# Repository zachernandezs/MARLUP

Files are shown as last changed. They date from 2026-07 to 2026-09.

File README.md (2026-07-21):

# MARLUP

MARLUP

Plataforma marina autoestabilizada para el lanzamiento de cohetes: 3 actuadores compensan roll, pitch y heave ante el oleaje. Desarrollado por **TECSpace**, la organización estudiantil de ingeniería aeroespacial del Instituto Tecnológico de Costa Rica (TEC).

## Índice

- [Contexto y evolución del proyecto](#contexto-y-evolución-del-proyecto)
- [Arquitectura física](#arquitectura-física)
  - [Geometría de la pirámide invertida](#geometría-de-la-pirámide-invertida)
  - [Modelo en espacio de estados](#modelo-en-espacio-de-estados)
  - [Actuadores](#actuadores)
  - [Sensores](#sensores)
  - [Perturbación por oleaje](#perturbación-por-oleaje)
- [Estrategia de control](#estrategia-de-control)
  - [LQR y matrices de ponderación](#lqr-y-matrices-de-ponderación)
  - [Filtro de Kalman discreto](#filtro-de-kalman-discreto)
  - [Extensión LQI (integrador de error)](#extensión-lqi-integrador-de-error)
  - [Precompensación / estado estacionario](#precompensación--estado-estacionario)
  - [Verificación PIL / SIL](#verificación-pil--sil)
- [Resultados de simulación](#resultados-de-simulación)
- [Estructura del repositorio](#estructura-del-repositorio)
- [Cómo ejecutar el modelo](#cómo-ejecutar-el-modelo)
- [Informes técnicos](#informes-técnicos)
- [Equipo](#equipo)

## Contexto y evolución del proyecto

El proyecto se ha desarrollado en dos etapas dentro del curso de Control:

| Etapa | Autoras/es | Alcance |
|---|---|---|
| **1 — Modelado inicial** | Hillary González González, Kendall Guerrero González | Modelado de la plataforma en *Simscape Multibody* (planta con pistones ideales, sensor ideal sin ruido) y control **PID individual por eje**. Solo simulación, sin prototipo físico. |
| **2 — Control óptimo** | Álvaro Pérez Mora, William Smith Hernández | Aproximación teórica simplificada de la planta, controlada con **LQR + estimador de Kalman**, y verificación del mismo controlador contra la planta simulada. Implementación en *Processor in the Loop* (PIL) sobre un Arduino MEGA. |

El repositorio actual (`MODELS/`) continúa esta línea de trabajo y **extiende el controlador LQR de la Etapa 2 con un integrador de error (LQI)**, para eliminar el error de estado estacionario sin depender únicamente de la precompensación *feedforward*.

La plataforma se modela como un sistema **MIMO no lineal** con tres actuadores lineales independientes cuya acción conjunta mantiene el plato superior nivelado.

## Arquitectura física

El sistema consiste en un plato circular superior (masa `M`, momentos de inercia `Jx`, `Jy`) sostenido por tres actuadores lineales dispuestos sobre una **pirámide triangular invertida**, anclada a la estructura de flotación de MARLUP.

### Geometría de la pirámide invertida

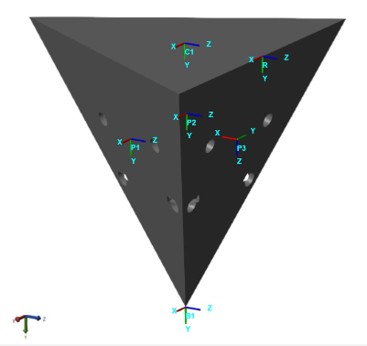
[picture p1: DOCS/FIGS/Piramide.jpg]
Esquema de la pirámide triangular invertida que sostiene el plato


*Esquema de la pirámide triangular invertida: los actuadores se ubican en las caras P1, P2, P3, con marco de referencia global R y marco del plato C1.*

**Dimensiones de la pirámide:**

- Altura: $H = 0.11\text{ m}$
- Radio circunscrito de la base: $R_b = 0.13\text{ m}$
- Radio de los puntos de aplicación en el plato: $R_t = 0.65\text{ m}$
- Ángulos de los actuadores sobre el plato: $\phi = \{-30°,\ 90°,\ 210°\}$

Los actuadores empujan perpendicularmente a cada cara de la pirámide. La componente vertical del vector unitario de empuje es común a los tres actuadores:

$$u_z = \frac{R_b}{\sqrt{R_b^2 + 4H^2}} \approx 0.5087$$

Cada punto de aplicación sobre el plato, respecto a su centroide, es:

$$\Delta \mathbf{r}_i = \begin{bmatrix} R_t \cos\phi_i \\ R_t \sin\phi_i \\ 0 \end{bmatrix}$$

Los esfuerzos generalizados del sistema $(\tau_x, \tau_y, F_z)$ se obtienen de las fuerzas de los tres actuadores $(F_1, F_2, F_3)$ mediante la **matriz de transformación** $T$:

$$\begin{bmatrix} \tau_x \\ \tau_y \\ F_z \end{bmatrix} = T \begin{bmatrix} F_1 \\ F_2 \\ F_3 \end{bmatrix}, \qquad T_i = \begin{bmatrix} R_t \sin\phi_i\, u_z \\ -R_t \cos\phi_i\, u_z \\ u_z \end{bmatrix}$$

Para $\phi = \{-30°, 90°, 210°\}$:

$$T = u_z \begin{bmatrix} -0.5 R_t & R_t & -0.5 R_t \\ -0.866 R_t & 0 & 0.866 R_t \\ 1 & 1 & 1 \end{bmatrix}$$

Para el reparto de fuerzas deseadas entre los tres actuadores se usa la pseudoinversa de $T$:

$$F = T^{+}\, u_{\text{des}}, \qquad T^{+} = \operatorname{pinv}(T)$$

### Modelo en espacio de estados

Considerando únicamente roll, pitch y heave, sin amortiguamiento ni rigidez, la dinámica del plato es un sistema lineal de segundo orden desacoplado:

$$J_x\ddot{\alpha} = \tau_x, \qquad J_y\ddot{\theta} = \tau_y, \qquad M\ddot{z} = F_z$$

En espacio de estados, $\dot{x} = Ax + Bu,\ \ y = Cx + Du$, con:

$$x = \begin{bmatrix}\alpha & \dot\alpha & \theta & \dot\theta & z & \dot z\end{bmatrix}^\top,\qquad u = \begin{bmatrix}\tau_x & \tau_y & F_z\end{bmatrix}^\top,\qquad y = \begin{bmatrix}\alpha & \theta & z\end{bmatrix}^\top$$

$$A = \begin{bmatrix} 0&1&0&0&0&0\\0&0&0&0&0&0\\0&0&0&1&0&0\\0&0&0&0&0&0\\0&0&0&0&0&1\\0&0&0&0&0&0 \end{bmatrix},\quad B = \begin{bmatrix} 0&0&0\\1/J_x&0&0\\0&0&0\\0&1/J_y&0\\0&0&0\\0&0&1/M \end{bmatrix},\quad C = \begin{bmatrix} 1&0&0&0&0&0\\0&0&1&0&0&0\\0&0&0&0&1&0 \end{bmatrix}$$

El sistema es controlable ($\operatorname{rank}(\operatorname{ctrb}(A,B)) = 6$) y se discretiza con retenedor de orden cero (ZOH) a un período de muestreo global $T_s = 0.01\text{ s}$, obteniendo $(A_d, B_d, C_d, D_d)$.

### Actuadores

Los actuadores planteados para la planta son cilindros **hidráulicos lineales Rexroth CDH1 MP3** (Bosch), seleccionados por su confiabilidad, estabilidad y capacidad de respuestas rápidas con fuerza significativa.

| Parámetro | Valor |
|---|---|
| Recorrido máximo del pistón | 1 m |
| Longitud total del actuador | 2 m |
| Presión del sistema | 250 bar |
| Área del pistón | 12.5 cm² |
| Área del anillo | 6.4 cm² |
| Carga aplicada | 58.19 kg |
| Alimentación eléctrica | 24 V DC a 200 mA |
| Desviación lineal | ≤ 500 mm |
| Resolución | 100 μm |

En el modelo teórico actual del repositorio, los actuadores se representan como ganancias ideales (torques/fuerza aplicados directamente a la planta); la dinámica realista del pistón (fricción, saturación, ancho de banda) se modeló por separado en Simscape durante la Etapa 2, pero no forma parte del modelo idealizado activo en `MODELS/`.

### Sensores

El sensado no ideal se modela con dos dispositivos:

- **3DM-GX5 AHRS** — entrega roll y pitch, con ruido blanco de banda limitada (BLWN) sumado a la señal.
- **MB1040** (ultrasónico) — entrega heave, con cuantización de 1 pulgada de resolución más ruido BLWN.

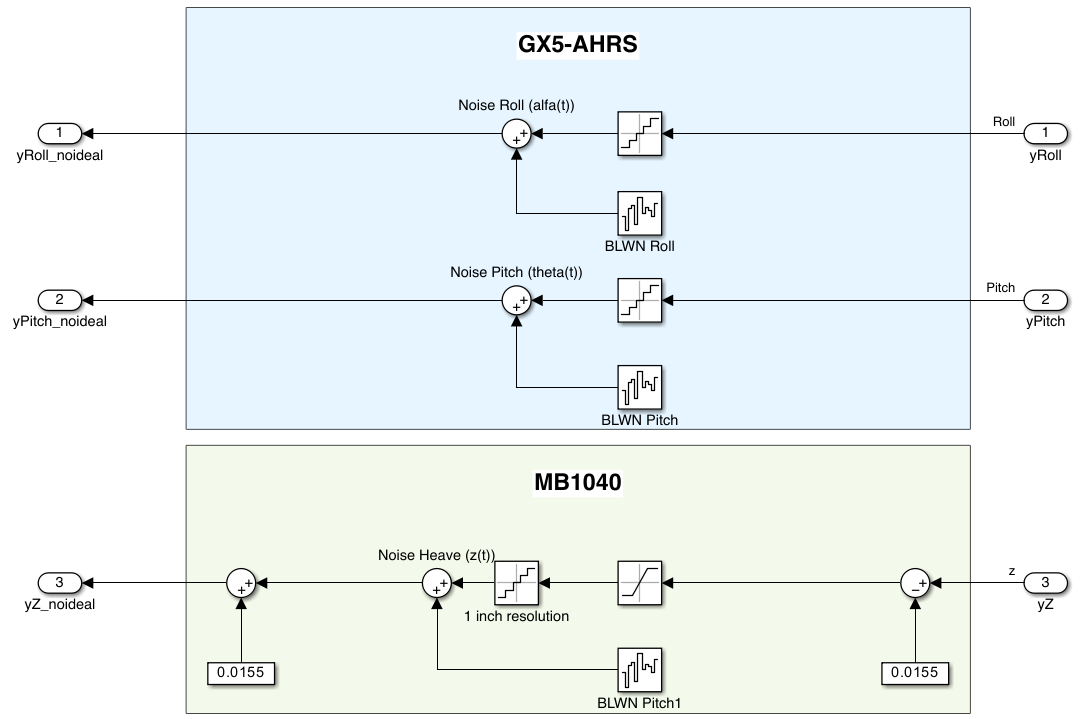
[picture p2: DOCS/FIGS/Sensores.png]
Modelo no ideal de los sensores seleccionados


*Modelo Simulink de los sensores no ideales: AHRS para roll/pitch y sensor ultrasónico para heave.*

### Perturbación por oleaje

El oleaje se modela como un disturbio de **salida**, no de estado:

$$y_{\text{total}} = Cx + P_{\text{reorder}}\, y_{\text{amb}}$$

El subsistema de oleaje entrega sus salidas en el orden `[heave; pitch; roll]`, mientras el modelo espera `[roll; pitch; heave]`; `P_reorder` corrige ese orden antes de sumar la perturbación.

La energía del oleaje se distribuye según el espectro de **Pierson-Moskowitz**, adecuado para mar completamente desarrollado (sin dependencia del viento):

$$S_\eta(\omega) = \frac{5}{16}\,\frac{H_s^2\,\omega_p^4}{\omega^5}\exp\!\left[-\frac{5}{4}\left(\frac{\omega_p}{\omega}\right)^{4}\right]$$

donde $\omega_p$ es la frecuencia pico del espectro y $H_s$ la altura significativa de ola. Este espectro se combina con una función de dispersión direccional (coseno cuadrado) para generar el oleaje 3D que perturba el eje $z$ y, mediante sus derivadas parciales en $x$ y $y$, los ángulos de roll y pitch.

## Estrategia de control

### LQR y matrices de ponderación

El controlador base es un **regulador lineal cuadrático (LQR)**: penaliza fuertemente el error de heave, medianamente el error angular, y levemente las velocidades y el esfuerzo de control.

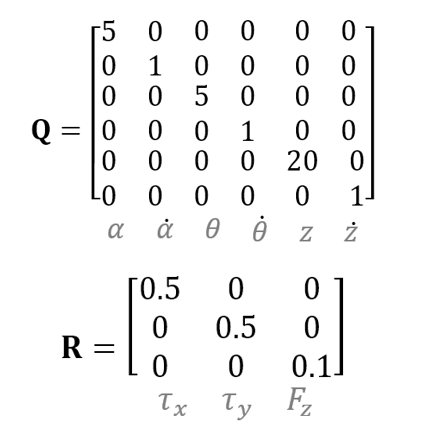
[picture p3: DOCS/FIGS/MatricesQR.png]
Matrices de ponderación Q y R del diseño LQR documentado en el informe


*Matrices $Q$ y $R$ del diseño LQR documentado en el informe de la Etapa 2. La implementación actual en `MODELS/marlup_init.m` reutiliza esta misma estructura de penalización, pero con ganancias reajustadas para el diseño LQI (ver más abajo).*

### Filtro de Kalman discreto

Dado que solo se sensan roll, pitch y heave (no sus velocidades), se requiere un estimador para reconstruir el vector de estado completo. Se emplea un **filtro de Kalman discreto** obtenido con `dlqe`:

$$\hat{x}(k+1\mid k) = A_d\,\hat{x}(k\mid k) + B_d\,u(k)$$

$$\hat{x}(k+1\mid k+1) = \hat{x}(k+1\mid k) + L_d\,\big(y(k+1) - C_d\,\hat{x}(k+1\mid k)\big)$$

La covarianza de proceso $Q_x$ pondera más las velocidades (mayor incertidumbre), y la de medición $R_n$ refleja el ruido real de los sensores: 0.5° en roll/pitch, 3 mm en heave.

### Extensión LQI (integrador de error)

Para eliminar el error de estado estacionario ante perturbaciones sostenidas de oleaje, el repositorio **aumenta la planta discreta con un integrador de error** por salida y diseña una ganancia LQI:

$$A_{\text{aug}} = \begin{bmatrix} A_d & 0 \\ -C_d A_d & I \end{bmatrix},\qquad B_{\text{aug}} = \begin{bmatrix} B_d \\ -C_d B_d \end{bmatrix}$$

$$K_{\text{aug}} = \operatorname{dlqr}(A_{\text{aug}}, B_{\text{aug}}, Q_{\text{aug}}, R) = \begin{bmatrix} K_x & K_i \end{bmatrix}$$

$$u(k) = -K_x\,\hat{x}(k) - K_i\, z_I(k), \qquad z_I(k) = \sum e(k),\ \ e = r - y_{\text{total}}$$

El diseño se valida además con la función `lqi` de MATLAB sobre el sistema discretizado como verificación cruzada. El diseño LQR continuo (`K`), su observador (`L`) y la ganancia de precompensación (`Kr`) se conservan como variante **sin integrador**; `Kr` no debe combinarse con el control LQI.

### Precompensación / estado estacionario

Para la variante sin integrador, el valor de estado estacionario se fija con una matriz *feedforward* $K_r$, resuelta de forma que $y_{ss} = r$:

$$y_{ss} = C\big(-(A-BK)^{-1}B\,K_r\big)r = r \quad\Longrightarrow\quad K_r = \operatorname{pinv}\!\big(C(-(A-BK)^{-1})B\big)$$

### Verificación PIL / SIL

El controlador LQR y el filtro de Kalman se validaron ejecutándolos en un **Arduino MEGA** mediante *Processor in the Loop* (PIL), en comunicación constante con la PC que simula el resto de la planta. Un interruptor en Simulink permite alternar entre PIL y *Software in the Loop* (SIL) para comparar ambas respuestas contra la misma simulación.

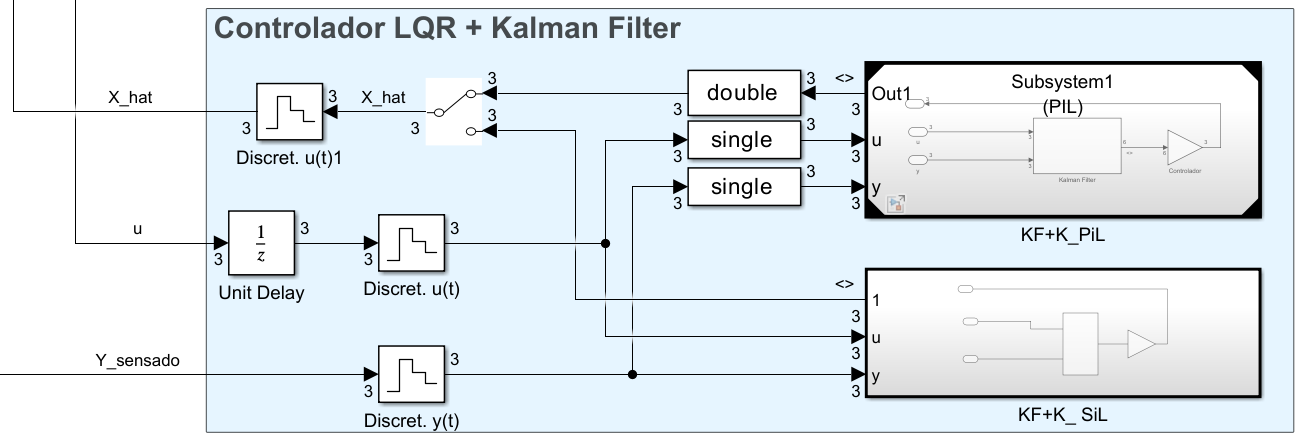
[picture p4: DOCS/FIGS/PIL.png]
Controlador LQR + Kalman Filter en configuración PIL y SIL


*Bloque de control en Simulink con las rutas PIL (ejecución en Arduino MEGA) y SIL (ejecución en PC), comparadas en paralelo.*

## Resultados de simulación

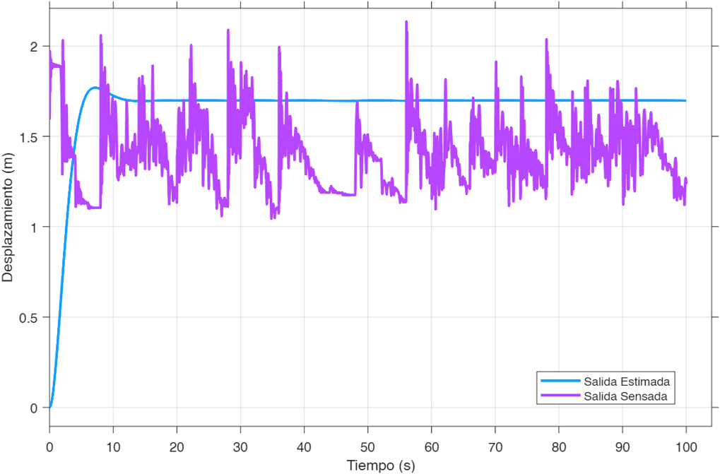
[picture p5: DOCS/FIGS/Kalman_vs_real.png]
Salida estimada del filtro de Kalman contra la salida sensada


*Heave: salida sensada (con ruido) contra la salida estimada por el filtro de Kalman, que filtra el ruido de medición y converge a la referencia.*

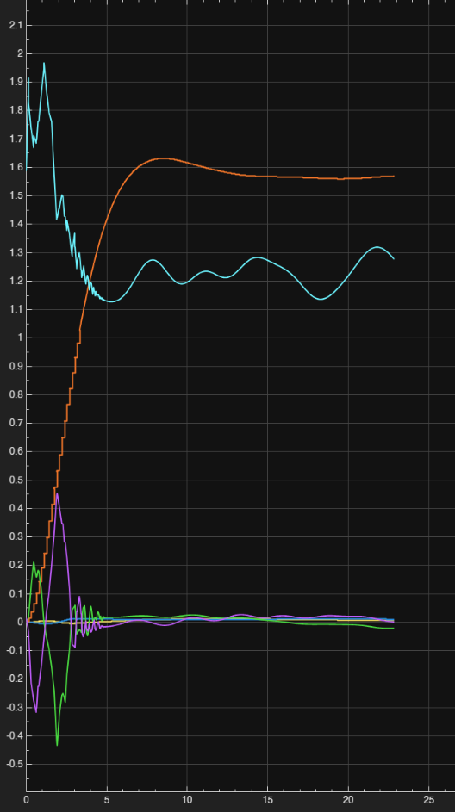
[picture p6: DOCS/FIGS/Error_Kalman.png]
Transitorio de estimación del filtro de Kalman


*Transitorio de estimación: las variables estimadas convergen desde la condición inicial hacia sus valores sensados, con el error de estimación decreciendo en el tiempo.*

Videos adicionales de las simulaciones (respuesta del modelo teórico, comparación con y sin Kalman, corridas fallidas de depuración) están disponibles en [`DOCS/FIGS/`](DOCS/FIGS/).

## Estructura del repositorio

```
MARLUP/
├── CAD/          Piezas SolidWorks (.SLDPRT) y ensamble principal (.SLDASM)
│                 usados por los bloques File Solid del modelo Simulink.
├── DOCS/         Informes finales (PDF) y DOCS/FIGS/ con figuras y videos de resultados.
├── MODELS/       Script MATLAB (marlup_init.m) + modelo Simulink (marlup_model.slx) activos.
└── EXPERIMENTS/  Copias de trabajo por integrante (Aaron/, Alvaro/, Will/) para
                  probar ajustes de ganancias de forma independiente.
```

## Cómo ejecutar el modelo

1. Abrir MATLAB en la raíz del repositorio y ejecutar `MODELS/marlup_init.m`. Esto define la planta, discretiza el sistema, calcula el filtro de Kalman y las ganancias de control, y las deja en el *workspace* (`Ad`, `Bd`, `Cd`, `Kx`, `Ki`, `Ld`, `T`, `Tinv`, `P_reorder`, etc.). También agrega `CAD/` al *path* para que el modelo encuentre la geometría por nombre.
2. Abrir `MODELS/marlup_model.slx` y correr la simulación — el modelo lee las variables anteriores del *workspace* base, por lo que falla si el script no se ejecutó antes en la misma sesión.
3. Todos los bloques discretos del modelo deben usar el mismo período de muestreo `Ts` definido en el script (`0.01 s`).

No hay sistema de *build*, gestor de paquetes ni suite de pruebas: todo el flujo vive dentro de MATLAB/Simulink.

## Informes técnicos

- [`DOCS/Final_Alvaro_Perez_William_Smith.pdf`](DOCS/Final_Alvaro_Perez_William_Smith.pdf) — *Avance Final MARLUP, Control Stage 2*: modelado teórico de la planta, diseño LQR + Kalman, actuadores, sensores, oleaje y verificación PIL/SIL.
- [`DOCS/InformeFinal_Proyecto_Lab_Control.pdf`](DOCS/InformeFinal_Proyecto_Lab_Control.pdf) — *Sistema de Control Activo para la Estabilización de la Plataforma MARLUP*: modelado inicial en Simscape Multibody y control PID individual por eje.

## Equipo

**TECSpace**, organización estudiantil de ingeniería aeroespacial del Instituto Tecnológico de Costa Rica (ITCR).

- Hillary González González, Kendall Guerrero González — Etapa 1 (modelado y PID).
- Álvaro Pérez Mora, William Smith Hernández — Etapa 2 (LQR + Kalman, PIL/SIL).
- Aaron, Álvaro, Will — ajuste de ganancias y experimentación continua (`EXPERIMENTS/`).

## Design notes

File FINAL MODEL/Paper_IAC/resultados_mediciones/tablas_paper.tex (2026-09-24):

% Tabla 7 (caso NORMAL): base & placa & reducción
Roll RMS & 0.3769 & 0.01994 & 18.9 (25.5 dB) \\
Pitch RMS & 0.1601 & 0.08101 & 2.0 (5.9 dB) \\
Heave RMS & 0.07018 & 0.07675 & 0.9 (-0.8 dB) \\
Roll peak & 0.7134 & 0.03903 & 18.3 \\
Pitch peak & 0.3765 & 0.1585 & 2.4 \\
Heave peak & 0.1245 & 0.09785 & 1.3 \\
Force range [min, max]: [203, 332] N (11.1 % de la capacidad)
Yaw drift: -0.128 deg (max 0.253 deg)

% Atenuación en w_p medida vs |S(jw_p)| (Tabla 6)
medido [roll pitch heave] = [-24.1 -11.1 -10.4] dB; teórico = [-31.2 -31.2 -37.8] dB

% Costo de cómputo por 10 s simulados (Tabla 8)
normal: 48.7 s

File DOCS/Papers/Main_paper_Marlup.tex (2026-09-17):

% ==================================================================
% IAC-26-D2.2.12.x114322 -- MARLUP paper skeleton
% Limit: 15 pages (US Letter, two columns), including abstract,
% figures and references; PDF only, max 5 MB; deadline 14 Sep 2026.
%
% Current length with placeholders: see compiled PDF (target <= 11 pages
% before the PiL and wave results are written; hard limit 15).
%
% Figures in pics/ (PNG). "real" = rendered from the TikZ/pgfplots
% sources in figsrc/ (data from the identification/LQR document);
% "placeholder" = to be replaced keeping the file name.
%   fig01_marlup_concept        placeholder  CAD render of the platform
%   fig02_geometry              real         side/top geometry
%   fig03_wave_disturbance      placeholder  P-M base motion
%   fig04_uz_comparison         real         assumed vs measured u_z
%   fig05_digital_twin          placeholder  Simscape Multibody model
%   fig06_ident_setup           real         identification configuration
%   fig07_ident_fit             real         roll-rate traces, fit window
%   fig08_poles                 real         closed-loop eigenvalues
%   fig09_control_architecture  real         closed loop with KF
%   fig10_pil_setup             placeholder  host PC <-> microcontroller
%   fig11_sil_vs_pil            placeholder  SiL vs PiL responses
%   fig12_sensitivity           real         |S(jw)| with P-M spectrum
%   fig13_step_forces           real         step responses + forces
%   fig14_digital_twin_waves    placeholder  double column, wave results
% Search for \todo{ and "TODO" to find every open item.
% ==================================================================
\documentclass[]{IAC_style}

% ------------------------------------------------------------------
% Additional packages (the class already loads graphicx, float,
% tabularx, booktabs, hyperref, cite and newtx fonts)
% ------------------------------------------------------------------
\usepackage{amsmath,bm} % symbols come from newtxmath (amssymb clashes with it)
\usepackage{xcolor}

% Editorial marker: prints red notes in the draft.
% For the final version replace the definition by \newcommand{\todo}[1]{}
\newcommand{\todo}[1]{\textcolor{red}{\textbf{[TODO:} #1\textbf{]}}}

% Notation
\newcommand{\W}{\bm{W}}
\newcommand{\Amat}{\bm{A}}
\newcommand{\Bmat}{\bm{B}}
\newcommand{\Cmat}{\bm{C}}
\newcommand{\Kmat}{\bm{K}}
\newcommand{\Mmat}{\bm{M}}
\newcommand{\Jmat}{\bm{J}}
\newcommand{\qv}{\bm{q}}
\newcommand{\xv}{\bm{x}}
\newcommand{\uv}{\bm{u}}
\newcommand{\Fv}{\bm{F}}
\newcommand{\cv}{\bm{c}}
\newcommand{\dd}{\mathrm{d}}
\newcommand{\un}[1]{\,\mathrm{#1}}
\newcolumntype{L}{>{\raggedright\arraybackslash}X}
\newcommand{\nom}[2]{\par\noindent\hangindent=2.6cm\hangafter=1\makebox[2.6cm][l]{#1}#2}

\begin{document}

\IACpaperyear{2026}
\IACconference{77}
\IACpapernumber{IAC-26,D2,2,12,x114322}
\IAClocation{Antalya, T\"urkiye}
\IACdate{5-9 October 2026}

% Copyright form B1 (retained by the author). Confirm the form selected
% in the IAF upload system; the wording must match it exactly.
\IACcopyrightB{Mr. \'Alvaro P\'erez Mora}

% Title must be identical to the accepted abstract.
\title{Development of an Actively Stabilized Marine Launch Platform for Small Rocket Launch Operations}

%\IACauthor{Author name}{affiliation index}{is corresponding author? 0-1}
\IACauthor{\'Alvaro P\'erez Mora$^{\orcidlink{0009-0004-1847-6741}}$}{2}{1}
\IACauthor{Aar\'on David Salas Alvarado$^{\orcidlink{0009-0001-7957-4546}}$}{2}{1} % TODO: add \orcidlink if available
\IACauthor{William Smith Hern\'andez$^{\orcidlink{0009-0003-1756-4718}}$}{2}{1}    % TODO: add \orcidlink if available

\IACauthoraffiliation{School of Electronics Engineering,Technical Institute of Costa Rica (ITCR), Cartago, Costa Rica.} % TODO: confirm e-mails

\abstract{
Costa Rica is a small contry of around 51,100 square kilometers of area, and it has extensive protected regions and scarce flat terrain, which constrains ground-based launch infrastructure and motivates alternative launch architectures. The MARLUP (Marine Launchpad) project proposes an actively stabilized floating launch platform for small rockets (motor classes A through H). The launch platform is based on a Stewart-type mechanism, with three linear actuators that control the roll, pitch and vertical displacement (heave) of the top plate, and mitigate the dominant disturbances induced by waves and tide. The dynamics were formulated from rigid-body mechanics as a nonlinear multi-input multi-output system and cast in state-space form. A digital twin was implemented in MATLAB/Simulink with Simscape Multibody from CAD geometry, including noisy, quantized and sampled sensor models and calm-sea disturbances generated from a Pierson-Moskowitz spectrum with directional spreading. Since the simplified analytic model used in earlier stages misrepresented the effective actuator geometry and inertia of the closed-chain mechanism, the force-to-acceleration map of the platform was identified directly from the digital twin through four short simulations and validated against an independent superposition prediction. On the identified model, an integral linear quadratic regulator with closed-form weights places the closed-loop bandwidth five to six times above the wave spectral peak, and a state estimator reconstructs the unmeasured states. The controller was discretized and executed in a Processor-in-the-Loop configuration, running on an embedded microcontroller while the digital twin was simulated in real time on a host computer. Compared with the previous decentralized and model-based control stages, the proposed strategy raises the wave attenuation at the spectral peak from $6$ dB to between $31$ and $38$ dB, settles within approximately $10$ s with minimal overshoot while holding the commanded heave, and reduces the simulation cost from hours to minutes. These results demonstrate the feasibility of an actively stabilized floating launch platform and establish a validated digital twin and control architecture for future experimental work and maritime launch infrastructure in emerging space nations.
}

\maketitle
\thispagestyle{fancy}

% ==================================================================
\section*{Nomenclature}
% Breakable list (a tabular cannot split across columns)
\nom{$\alpha,\ \theta$}{roll and pitch angles of the plate (rad)}
\nom{$z$}{heave, plate height (m)}
\nom{$\qv$}{generalized coordinates $[\alpha\ \theta\ z]^\top$}
\nom{$\xv$}{state vector $[\alpha\ \dot\alpha\ \theta\ \dot\theta\ z\ \dot z]^\top$}
\nom{$\Fv$}{actuator force vector $[F_1\ F_2\ F_3]^\top$ (N)}
\nom{$\Fv_\mathrm{trim}$}{static equilibrium force vector (N)}
\nom{$\W$}{force-to-acceleration map ($3\times3$)}
\nom{$\cv$}{gravitational bias acceleration}
\nom{$\Mmat(\qv),\ \Jmat(\qv)$}{generalized inertia matrix, inverse-kinematics Jacobian}
\nom{$\bm{\xi}$}{integral state}
\nom{$H_s,\ T_p,\ \omega_p$}{significant wave height, peak period, peak frequency}
\nom{$\omega_n,\ \zeta,\ \omega_i$}{closed-loop natural frequency, damping ratio, integrator pole}
\nom{$u_z$}{vertical direction cosine of an actuator}
\nom{$T_s$}{controller sampling period (s)}
\par

\section*{Acronyms/Abbreviations}
Attitude and heading reference system (AHRS), degree of freedom (DOF), Kalman filter (KF), linear quadratic regulator (LQR), Marine Launchpad (MARLUP), multi-input multi-output (MIMO), Pierson--Moskowitz (P--M), Processor-in-the-Loop (PiL), Software-in-the-Loop (SiL), zero-order hold (ZOH).

% ==================================================================
\section{Introduction}
\label{sec:intro}
Access to launch infrastructure remains one of the main barriers for emerging space nations. Ground-based launch sites require large uninhabited areas, safety exclusion zones along the flight corridor and stable, flat terrain. Costa Rica combines a small national territory, a large fraction of land under environmental protection and a mountainous topography, which makes a conventional launch range, even for small suborbital vehicles, difficult to justify. % TODO: add a source for land area and protected-area fraction (e.g., SINAC).
Launching from the sea removes most of these constraints, since the launch site can be relocated to open water where range safety is easier to guarantee.

Sea-based launch has precedents at very different scales, from the fixed San Marco platform off the coast of Kenya to the floating Sea Launch system and the more recent ship-based launches of small orbital vehicles \cite{sanmarco,sealaunch}. For small rockets, however, the floating base is itself a moving support: wave-induced roll, pitch and heave perturb the alignment of the launch rail and the initial attitude of the vehicle at lift-off. Parallel mechanisms derived from the Stewart platform \cite{stewart1965,dasgupta2000,merlet2006} are the established solution for compensating such motions, and active motion compensation is routinely used offshore, for example in motion-compensated gangways for wind turbine access \cite{cerda2010}. A reduced three-actuator architecture that controls only roll, pitch and heave addresses the motions that dominate launch alignment while keeping mass, cost and power consumption compatible with a student-led project.

The MARLUP project, developed within TECSpace at the Instituto Tecnol\'ogico de Costa Rica, follows this approach. The hexagonal floating base was sized from buoyancy and stability criteria \cite{perez2025flot}. A first Simscape Multibody model of the stabilization mechanism was controlled with one decentralized PID loop per axis, under sinusoidal waves and ideal sensors, and required several hours of computation for a few seconds of response \cite{gonzalez2025}. A second stage replaced the PID loops with a linear quadratic regulator (LQR) and a KF designed on a simplified analytic model, added a P--M wave model and non-ideal sensors, and executed the controller on a microcontroller in a PiL configuration; applied to the multibody digital twin, however, this controller achieved only marginal stability for about 20 s \cite{perez2025stage2}. The recommendation of that stage was to identify the simulated plant instead of assuming it.

This paper reports the resulting design. Its contributions are a digital twin of the platform with realistic disturbances and sensing, a diagnosis of why the rigid-body simplification commonly used for such platforms fails for a closed-chain mechanism whose legs are comparable in size to the plate, a non-invasive identification procedure that is exact at the operating point and is validated by an independent prediction, an integral LQR with closed-form weights whose bandwidth is placed deliberately with respect to the wave spectrum, and the execution of the discretized controller and estimator in PiL. Section~\ref{sec:system} describes the system and its environment, Section~\ref{sec:model} the dynamic model, Section~\ref{sec:ident} the identification, Section~\ref{sec:control} the control and estimation design, Section~\ref{sec:pil} the PiL implementation, Section~\ref{sec:results} the results, and Section~\ref{sec:concl} the conclusions.

% ==================================================================
\section{System description}
\label{sec:system}

\subsection{Launch platform concept}
The MARLUP concept, shown in Fig.~\ref{fig:cad}, consists of a hexagonal floating base with six lateral floats and a central float, sized by Archimedes' principle to carry the structure, the launch plate and the lift-off load with a $25\%$ margin \cite{perez2025flot}. The stabilization mechanism is mounted on the floating base and carries the launch plate, which must remain level and at a commanded height during launch preparation and lift-off. The operating envelope is restricted to calm-sea launch windows. \todo{state the design sea state ($H_s$ range) and the target rocket envelope (mass, rail length).}

\begin{figure}[H]
\centering

\caption{MARLUP concept: hexagonal floating base, three-actuator stabilization mechanism and launch plate (SolidWorks model).}
\label{fig:cad}
\end{figure}

\subsection{Stabilization mechanism}
The moving platform is a circular plate of mass $M=67.7\un{kg}$ carried by three linear actuators (Fig.~\ref{fig:geom}). The lower anchors lie on a small inverted triangular pyramid ($H=0.11\un{m}$, circumscribed radius $R_b=0.13\un{m}$) attached to the floating structure through a four-DOF joint. The upper anchors are distributed on a circle of radius $R_t=0.65\un{m}$ at azimuths $\varphi_i=\{-30^\circ,90^\circ,210^\circ\}$, and the plate rests at $z_0=1.5716\un{m}$ in the assembled configuration. The actuators are modeled after a double-acting hydraulic cylinder (Bosch Rexroth CDH1 MP3, $250$ bar, $12.5\un{cm^2}$ piston area, $\pm0.28\un{m}$ usable stroke) and are represented in the digital twin as ideal force sources. The controlled coordinates are $\qv=[\alpha\ \theta\ z]^\top$.

\begin{figure}[H]
\centering

\caption{Geometry of the stabilization mechanism (schematic, not to scale): side view with the measured actuator inclination of $34.3^\circ$ from vertical, and top view of the plate anchors.}
\label{fig:geom}
\end{figure}

\subsection{Sensing}
Roll and pitch are measured by an AHRS model based on the 3DM-GX5 and heave by an ultrasonic range sensor model based on the MB1040. Each measurement includes additive white Gaussian noise and quantization, and all signals are sampled at $T_s=10\un{ms}$, the period of the PiL target. \todo{list noise standard deviations and quantization steps used.}

\subsection{Wave disturbance model}
The sea state is generated from the P--M spectrum \cite{pm1964,fossen2011},
\begin{equation}
S_\eta(\omega)=\frac{5}{16}\,\frac{H_s^2\,\omega_p^4}{\omega^5}\exp\!\left[-\frac{5}{4}\left(\frac{\omega_p}{\omega}\right)^{4}\right],
\label{eq:pm}
\end{equation}
combined with a $\cos^2$ directional spreading function. The peak period $T_p=10\un{s}$ gives $\omega_p=2\pi/T_p=0.628\un{rad/s}$, the frequency that governs the control specification of Section~\ref{sec:control}. The free-surface elevation at the origin defines the heave of the base, and its spatial gradients define the base roll and pitch, which are imposed through the four-DOF joint (Fig.~\ref{fig:waves}). \todo{state $H_s$, number of wave components and seed.}

\begin{figure}[H]
\centering

\caption{Base motion generated by the P--M model ($T_p=10$ s): heave, roll and pitch imposed on the floating structure.}
\label{fig:waves}
\end{figure}

% ==================================================================
\section{Dynamic model and digital twin}
\label{sec:model}

\subsection{Rigid-body formulation}
For a rigid multibody mechanism with independent generalized coordinates $\qv$, Lagrangian mechanics gives \cite{merlet2006}
\begin{equation}
\Mmat(\qv)\,\ddot{\qv}+\bm{h}(\qv,\dot{\qv})=\Jmat(\qv)^\top\Fv .
\label{eq:eom}
\end{equation}
The generalized inertia matrix $\Mmat(\qv)=\sum_k\big[\Jmat_{v,k}^\top m_k\Jmat_{v,k}+\Jmat_{\omega,k}^\top\bm{I}_k\Jmat_{\omega,k}\big]$ contains every moving body (plate, upper triangle and leg segments). The vector $\bm{h}$ collects gravity and the Coriolis and centrifugal terms, the latter quadratic in $\dot{\qv}$. The inverse-kinematics Jacobian $\Jmat(\qv)=\partial\bm{\ell}/\partial\qv$, with $\bm{\ell}$ the leg lengths, has rows $\bm{u}_i^\top\partial\bm{p}_i/\partial\qv$, where $\bm{u}_i=(\bm{p}_i-\bm{b}_i)/\ell_i$ is the unit vector from the base anchor $\bm{b}_i$ to the plate anchor $\bm{p}_i$. Equation~\eqref{eq:eom} defines a nonlinear, configuration-dependent MIMO plant.

Evaluated at the assembled pose $\qv_0$ with the plate at rest, $\Mmat$, $\bm{h}$ and $\Jmat$ become constant and every velocity-dependent term vanishes identically, so that
\begin{equation}
\begin{gathered}
\ddot{\qv}=\W\Fv+\cv,\\
\W=\Mmat(\qv_0)^{-1}\Jmat(\qv_0)^\top,\qquad \cv=-\Mmat(\qv_0)^{-1}\bm{h}(\qv_0,\bm{0}).
\end{gathered}
\label{eq:affine}
\end{equation}
This affine relation between forces and accelerations is exact at that point, not a linearization; it only assumes rigid bodies and evaluation at rest, both of which hold by construction at the start of a simulation from the assembled configuration. The Gr\"ubler--Kutzbach criterion applied to the Simscape topology ($N=14$ links, $j=15$ joints, $\sum f_i=15$ joint freedoms) gives $6(N-1-j)+\sum f_i=3$ DOF for the plate. The yaw freedom of the base joint is unactuated and unmeasured, and lies outside the model.

\subsection{Limitations of the simplified analytic model}
\label{sec:whyfail}
The previous stage \cite{perez2025stage2} took the plate as a free rigid body, $J_x\ddot\alpha=\tau_x$, $J_y\ddot\theta=\tau_y$, $M\ddot z=F_z$, with the bare-plate inertias $J_x=J_y=6.194\un{kg\,m^2}$ and $M=67.71\un{kg}$, and mapped the actuator forces to generalized efforts through a constant allocation matrix,
\begin{equation}
\begin{bmatrix}\tau_x\\ \tau_y\\ F_z\end{bmatrix}=\bm{T}\Fv,\qquad
\bm{T}_{(:,i)}=u_z\begin{bmatrix}R_t\sin\varphi_i\\ -R_t\cos\varphi_i\\ 1\end{bmatrix},
\label{eq:Told}
\end{equation}
so that $\W_\mathrm{assumed}=\mathrm{diag}(J_x,J_y,M)^{-1}\bm{T}$. Both factors are incorrect, and independently so.

The vertical direction cosine was taken as that of the normal to a face of the base pyramid, $u_z=R_b/\sqrt{R_b^2+4H^2}=0.509$, which describes a real part of the mechanism but not the direction along which an actuator pushes. The actuators act along the line joining a base anchor to a plate anchor $1.57\un{m}$ above it, for which the assembled model gives $u_z=0.826$, i.e. $34.3^\circ$ instead of $59.4^\circ$ from vertical, a factor of $1.62$ (Fig.~\ref{fig:uz}). The inertia factor is wrong because the plate is the moving platform of a closed-chain mechanism: tilting it requires all legs to change length and swing, and translates the plate laterally, so every leg body contributes to $\Mmat$. With the analytic geometry, the tilt inertia consistent with the measurements of Section~\ref{sec:ident} is about $57.8\un{kg\,m^2}$, nine times the bare-plate value and plausibly bracketed by the bare disc ($6.2\un{kg\,m^2}$) and a $67.7\un{kg}$ point mass at the plate height ($mL^2=167\un{kg\,m^2}$).

\begin{figure}[H]
\centering

\caption{Candidate actuator directions. The simplified model used the normal to a face of the base pyramid; the actuators run between anchors. Their vertical projections differ by a factor of $1.62$.}
\label{fig:uz}
\end{figure}

Scaling the identified map back through the nominal inertias, $\bm{T}_\mathrm{ident}=\mathrm{diag}(J_x,J_y,M)\W$, allows a direct comparison,
\begin{equation}
\begin{gathered}
\bm{T}_\mathrm{assumed}=\begin{bmatrix}
-0.165 & 0.331 & -0.165\\
-0.286 & 0 & 0.286\\
0.509 & 0.509 & 0.509\end{bmatrix},\\
\bm{T}_\mathrm{ident}=\begin{bmatrix}
-0.017 & 0.036 & -0.018\\
-0.031 & 0.000 & 0.030\\
0.835 & 0.826 & 0.816\end{bmatrix},
\end{gathered}
\label{eq:Tcompare}
\end{equation}
which differ by $71.4\%$ in Frobenius norm. The comparison also shows what survives: the third row of $\bm{T}_\mathrm{ident}$ is uniform within $2.3\%$, as the symmetric arrangement requires, and the $(2,2)$ entry vanishes in both matrices, since the $90^\circ$ leg has no moment arm about the pitch axis. The azimuthal structure of the earlier model was correct and only its scaling was wrong. This is the expected failure of the free-platform simplification, which is adequate for serial or lightly loaded mechanisms but not for a closed chain whose legs are comparable in mass and length to the plate.

Moreover, input--output data determine only the product $\W=\Mmat^{-1}\Jmat^\top$: assuming the bare-plate inertia yields $\Jmat^\top=\bm{T}_\mathrm{ident}$, assuming the analytic geometry yields $\Mmat=\mathrm{diag}(57.8,57.9,41.7)$, and both reproduce every measurement. A full derivation through \eqref{eq:eom} would require the anchor coordinates and mass properties of about eleven bodies from CAD, and would still need validation against measurements, so $\W$ is measured directly.

\subsection{Digital twin}
The digital twin (Fig.~\ref{fig:twin}) was built in Simscape Multibody \cite{simscape} from the SolidWorks assembly, preserving the masses, inertias and joint topology of the mechanism, and integrates the wave model and the sensor models of Section~\ref{sec:system}. The plant subsystem has the three actuator forces as inputs and roll, pitch, heave and their rates as outputs, with angles reported in degrees; the conversion $\bm{S}=\mathrm{diag}(\pi/180,\pi/180,\pi/180,\pi/180,1,1)$ is applied ahead of the controller, since an unnoticed factor of $57.3$ in the feedback path would act as a gain error. The model is integrated with \texttt{ode23t} at $\mathrm{RelTol}=10^{-4}$ and $\mathrm{AbsTol}=10^{-6}$; tolerances of $10^{-2}$, used in earlier versions, are looser than the controlled signals themselves, which are of order $10^{-3}\un{rad}$.

\begin{figure}[H]
\centering

\caption{Digital twin of MARLUP in Simscape Multibody: mechanism, wave input through the four-DOF base joint and sensor models.}
\label{fig:twin}
\end{figure}

% ==================================================================
\section{Plant identification}
\label{sec:ident}

\subsection{Experiment design}
The affine map \eqref{eq:affine} has twelve unknowns, nine in $\W$ and three in $\cv$, and is therefore fixed by its value at four points. Four simulations are run from rest at $\qv_0$ with a flat sea, the feedback path opened and the allocation gain set to identity, so that a constant block injects the actuator forces directly (Fig.~\ref{fig:idsetup}). With $\bm{e}_i$ the $i$-th unit vector and a probe force $\delta F$,
\begin{equation}
\Fv=\bm{0}\Rightarrow\ddot{\qv}=\cv,\qquad
\Fv=\delta F\,\bm{e}_i\Rightarrow\W_{(:,i)}=\frac{\ddot{\qv}_i-\cv}{\delta F},
\label{eq:runs}
\end{equation}
and the force that holds the plate stationary follows from $\ddot{\qv}=\bm{0}$ as
\begin{equation}
\Fv_\mathrm{trim}=-\W^{-1}\cv .
\label{eq:Ftrim}
\end{equation}
A fifth run with $\Fv=\delta F[1\ 1\ 1]^\top$ is not used for fitting: it is predicted from the other four and then measured, which makes the affine assumption falsifiable, since an engaged joint limit or an appreciable change of configuration during the window would make the prediction miss. The probe $\delta F=400\un{N}$ is large enough for the resulting accelerations to dominate solver noise and small enough for the plate to move only microns during the measurement. Only controller-path parameters are altered, and they are restored automatically on exit, including on error; the plant subsystem is never modified.

\begin{figure}[H]
\centering

\caption{Configuration for the identification runs: feedback gain and reference zeroed, allocation gain set to identity, and significant wave height set to zero so that the base is stationary.}
\label{fig:idsetup}
\end{figure}

\subsection{Recovery of accelerations}
The plant outputs positions and velocities. Differentiating a velocity signal numerically amplifies solver noise, and filtering it introduces a lag that biases the very quantity being measured. Under a constant force applied from rest, however, each velocity satisfies $v(t)=\ddot q(0)\,t+\mathcal{O}(t^2)$, so the acceleration is the slope at the origin. Minimizing $\sum_k(v_k-a\,t_k)^2$ with the intercept constrained to zero gives
\begin{equation}
\ddot q=\frac{\sum_k t_k v_k}{\sum_k t_k^2},
\label{eq:slope}
\end{equation}
which has no tuning parameters and introduces no lag. The fit window is $t\in[4,40]\un{ms}$ (Fig.~\ref{fig:fit}): the lower bound discards four time constants of the $1\un{ms}$ input filter of the physical-signal conversion, and the upper bound keeps the quadratic term negligible. These runs use \texttt{ode23t} with a maximum step of $0.5\un{ms}$, $\mathrm{RelTol}=10^{-6}$ and $\mathrm{AbsTol}=10^{-8}$, which guarantees at least 70 samples in the window. Each run lasts $60\un{ms}$ of simulated time, and the complete identification takes about $5\un{s}$ of computation.

\begin{figure}[H]
\centering

\caption{Roll rate in the four identification runs. Each trace is a straight line through the origin whose slope, obtained from \eqref{eq:slope}, gives one entry of $\ddot{\qv}$.}
\label{fig:fit}
\end{figure}

\subsection{Identified model and validation}
Table~\ref{tab:accs} lists the measured accelerations. Applying \eqref{eq:runs} and \eqref{eq:Ftrim},
\begin{equation}
\W=10^{-3}\!\begin{bmatrix}
-2.772 & 5.739 & -2.924\\
-5.027 & 0.007 & 4.872\\
12.336 & 12.191 & 12.054
\end{bmatrix},\quad
\cv=\begin{bmatrix}-0.036\\ 0.224\\ -9.924\end{bmatrix},
\label{eq:Wnum}
\end{equation}
with rows in $\mathrm{rad\,s^{-2}N^{-1}}$ (roll, pitch) and $\mathrm{m\,s^{-2}N^{-1}}$ (heave), $\Fv_\mathrm{trim}=[288.5\ \ 273.7\ \ 251.3]^\top\un{N}$, $\det\W=1.04\times10^{-6}$ and $\mathrm{cond}(\W)=3.02$. The free-fall bias $c_3=-9.924\un{m/s^2}$ exceeds $g$ because the unpowered plate also drags the leg linkage, a first confirmation that the linkage inertia is not negligible.

\begin{table}[H]
\centering
\caption{Measured generalized accelerations (rad/s$^2$, rad/s$^2$, m/s$^2$).}
\label{tab:accs}
\footnotesize
\begin{tabular}{@{}lrrrl@{}}
\toprule
$\Fv^\top$ (N) & $\ddot\alpha$ & $\ddot\theta$ & $\ddot z$ & gives\\
\midrule
$[0\ \ 0\ \ 0]$       & $-0.0360$ & $0.2242$  & $-9.9244$ & $\cv$\\
$[400\ \ 0\ \ 0]$     & $-1.1448$ & $-1.7867$ & $-4.9902$ & $\W_{(:,1)}$\\
$[0\ \ 400\ \ 0]$     & $2.2596$  & $0.2271$  & $-5.0479$ & $\W_{(:,2)}$\\
$[0\ \ 0\ \ 400]$     & $-1.2055$ & $2.1730$  & $-5.1029$ & $\W_{(:,3)}$\\
\midrule
$[400\ 400\ 400]$     & $-0.0187$ & $0.1653$  & $4.7157$  & check\\
\bottomrule
\end{tabular}
\end{table}

Table~\ref{tab:valid} summarizes the validation battery. The superposition prediction, $\W[400\ 400\ 400]^\top+\cv=[-0.0187\ \ 0.1650\ \ 4.7078]^\top$, matches the measured fifth run with a relative error of $1.68\times10^{-3}$; since the plate then accelerates upward at $4.72\un{m/s^2}$, the probe straddles the trim point, which is the regime in which the controller operates. The static closure compares the trim forces resolved along the identified leg direction, $(\sum_iF_{\mathrm{trim},i})\,\bar u_z=813.48\times0.826=671.93\un{N}$, with the weight implied by the free-fall run, $M|c_3|=671.97\un{N}$; because $\bar u_z$ is itself derived from the third row of $\W$, this is a consistency check bounded by the $2.3\%$ spread of that row rather than a fully independent test. The pitch entry of the $90^\circ$ leg, $W_{22}=7.25\times10^{-6}$, is five orders of magnitude below the largest entry and is therefore numerically zero, as the geometry requires. Finally, the low condition number shows that $\qv_0$ is far from a kinematic singularity. An analytic linearization of the Simscape model, in which the first Markov parameter $\Cmat\Bmat$ of the velocity outputs equals $\W$, provides an independent algorithmic cross-check. \todo{report the Route C (\texttt{linearize}) comparison or remove this sentence.}

\begin{table}[H]
\centering
\caption{Validation of the identified model.}
\label{tab:valid}
\footnotesize
\begin{tabularx}{\columnwidth}{@{}>{\raggedright\arraybackslash}p{2.2cm}LL@{}}
\toprule
Check & Result & Rules out\\
\midrule
Superposition prediction & $1.68\times10^{-3}$ rel.\ error & nonlinearity, active joint limits\\
Static equilibrium & $671.93$ vs $671.97$ N & sign and routing errors\\
Zero arm of $90^\circ$ leg & $W_{22}/\max|W_{ij}|=5.9\times10^{-4}$ & wrong leg assignment\\
Inter-leg symmetry & $2.3\%$ spread in $\W_{(3,:)}$ & mis-assembled leg\\
Conditioning & $\mathrm{cond}(\W)=3.02$, $\mathrm{rank}\,\mathcal{C}=6$ & kinematic singularity\\
\bottomrule
\end{tabularx}
\end{table}

The procedure is non-invasive, reproducible and falsifiable, and requires only the \texttt{sim} command.

\subsection{State-space model}
With $\xv=[\alpha\ \dot\alpha\ \theta\ \dot\theta\ z\ \dot z]^\top$ and the input in deviation form, $\uv=\Fv-\Fv_\mathrm{trim}$, the plant is
\begin{equation}
\dot{\xv}=\Amat\xv+\Bmat\uv,\qquad \bm{y}=\Cmat\xv,
\label{eq:ss}
\end{equation}
with $\Amat=\mathrm{blkdiag}(\bm{A}_0,\bm{A}_0,\bm{A}_0)$, $\bm{A}_0=[0\ 1;\,0\ 0]$, $\Bmat$ having zero odd rows and the rows of $\W$ as its even rows, and $\Cmat$ selecting $\alpha$, $\theta$ and $z$. The matrix $\Amat$ encodes only kinematics: the mechanism has no springs and negligible joint damping ($1.5\times10^{-4}\un{N\,s/m}$), gravity enters as the constant $\cv$ cancelled by $\Fv_\mathrm{trim}$, and all cross-coupling lies in the measured off-diagonal entries of $\W$. The model therefore consists of three double integrators driven through a single, fully coupled input matrix. The controllability matrix has rank 6, which follows directly from $\W$ being nonsingular, and the pair $(\Amat,\Cmat)$ is observable, so the rates can be reconstructed from the three measured positions. The model is valid near $\qv_0$, within a heave range bounded by the actuator stroke, estimated at $z_0\pm0.13\un{m}$, and a few degrees of tilt. \todo{verify the $\pm0.13$ m range against the stroke limits.}

% ==================================================================
\section{Control and estimation design}
\label{sec:control}

\subsection{Decoupling and allocation}
Since $\W$ is square and well conditioned, the virtual input
\begin{equation}
\bm{v}=\W(\Fv-\Fv_\mathrm{trim})\quad\Longrightarrow\quad\ddot{\qv}=\bm{v}
\label{eq:virtual}
\end{equation}
turns the plant into three independent unit double integrators, and the actuator forces are recovered as $\Fv=\Fv_\mathrm{trim}+\W^{-1}\bm{v}$. This is the role the inverse allocation $\bm{T}^{-1}$ played in the previous design, now with a measured rather than an assumed matrix. The condition number $3.02$ bounds the amplification of identification errors by the inversion to a factor of three; for a poorly conditioned map, say $\mathrm{cond}(\W)>20$, the design should instead be carried out directly on $(\Amat,\Bmat)$.

\subsection{Integral LQR}
One integral state per controlled output, $\dot{\bm\xi}=\bm{r}-\Cmat\xv$, removes the steady-state error caused by the mean component of the disturbance and by any residual mismatch in $\Fv_\mathrm{trim}$, which would otherwise appear directly as a standing heave offset. The augmented pair is
\begin{equation}
\Amat_a=\begin{bmatrix}\Amat & \bm{0}_{6\times3}\\ -\Cmat & \bm{0}_{3\times3}\end{bmatrix},\qquad
\Bmat_a=\begin{bmatrix}\Bmat\\ \bm{0}_{3\times3}\end{bmatrix},
\label{eq:augment}
\end{equation}
and the controller minimizes \cite{anderson1990}
\begin{equation}
\mathcal{J}=\int_0^\infty\left(\xv^\top\bm{Q}\xv+\bm\xi^\top\bm{Q}_i\bm\xi+\uv^\top\bm{R}\uv\right)\dd t,
\label{eq:cost}
\end{equation}
with $\bm{Q}$ and $\bm{Q}_i$ diagonal and $\bm{R}=\W^\top\W$. From \eqref{eq:virtual}, this choice gives $\uv^\top\bm{R}\uv=\bm{v}^\top\bm{v}$, so the controller is charged for the generalized acceleration it commands rather than for newtons. Since the effective inertias of the three axes differ by about an order of magnitude, a newton spent on heave and a newton spent on roll buy very different control authority, and weighting them equally would silently over-penalize the stiffer axis. The choice also separates the $9\times9$ Riccati equation exactly into three scalar-input problems. The resulting law is
\begin{equation}
\Fv=\Fv_\mathrm{trim}+\Kmat_x(\xv_\mathrm{ref}-\xv)+\Kmat_i\bm\xi .
\label{eq:law}
\end{equation}

\subsection{Bandwidth and closed-form weights}
A feedback loop rejects disturbances below its bandwidth and follows them above it, so the closed-loop bandwidth must lie well above the wave peak $\omega_p=0.628\un{rad/s}$. The previous design sat at about $0.65\un{rad/s}$, essentially the bandwidth of the sea, and therefore tracked the waves instead of rejecting them, which alone explains its observed behavior. Each axis is now specified by $(s^2+2\zeta\omega_n s+\omega_n^2)(s+\omega_i)=s^3+k_ds^2+k_ps+k_i$, whose coefficients give the per-axis gains of the unit double integrator,
\begin{equation}
k_d=2\zeta\omega_n+\omega_i,\quad k_p=\omega_n^2+2\zeta\omega_n\omega_i,\quad k_i=\omega_n^2\omega_i,
\label{eq:kpkdki}
\end{equation}
with the values in Table~\ref{tab:spec}. The natural frequencies place the loop $4.8$ and $6.4$ times above $\omega_p$; the upper limit comes from actuator bandwidth and solver cost rather than from the algebra.

The weights are not hand-tuned: they are those for which the LQR places its poles exactly on this specification. For one decoupled axis, $\ddot q=v$ with $\dot\xi=-q$, weights $(q_\alpha,q_d,q_i)$ on position, rate and integral, and unit input weight (which is what $\bm{R}=\W^\top\W$ delivers in virtual coordinates), the transfer from $v$ to the states is $\bm{G}(s)=[1/s^2\ \ 1/s\ \ {-1/s^3}]^\top$. The optimal poles are the stable roots of the return-difference equation $1+\bm{G}(-s)^\top\bm{Q}_\mathrm{axis}\bm{G}(s)=0$ \cite{kwakernaak1972}, which reduces to
\begin{equation}
s^6-q_d\,s^4+q_\alpha\,s^2-q_i=0 .
\label{eq:rd}
\end{equation}
Requiring these roots to coincide with those of $\phi(s)=s^3+k_ds^2+k_ps+k_i$ means that \eqref{eq:rd} must equal $-\phi(s)\phi(-s)=s^6-(k_d^2-2k_p)s^4-(2k_dk_i-k_p^2)s^2-k_i^2$, so that $q_d=k_d^2-2k_p$, $q_\alpha=k_p^2-2k_dk_i$ and $q_i=k_i^2$. Substituting \eqref{eq:kpkdki},
\begin{equation}
\begin{aligned}
q_\alpha&=\omega_n^2\left[\omega_n^2+2\omega_i^2(2\zeta^2-1)\right],\\
q_d&=2\omega_n^2(2\zeta^2-1)+\omega_i^2,\qquad q_i=\omega_n^4\omega_i^2 .
\end{aligned}
\label{eq:weights}
\end{equation}
Positive semidefiniteness requires $2\zeta^2-1\geq0$, i.e. $\zeta\geq1/\sqrt2$, a second and independent reason for $\zeta=0.9$. For the roll axis, $2\zeta^2-1=0.62$ gives $q_d=11.72$, $q_\alpha=87.28$ and $q_i=45.56$.

\begin{table}[H]
\centering
\caption{Closed-loop specification, LQR weights and equivalent per-axis gains.}
\label{tab:spec}
\footnotesize
\setlength{\tabcolsep}{3.2pt}
\begin{tabular}{@{}lccccccccc@{}}
\toprule
Axis & $\omega_n$ & $\zeta$ & $\omega_i$ & $q_\alpha$ & $q_d$ & $q_i$ & $k_p$ & $k_d$ & $k_i$\\
\midrule
Roll  & 3.0 & 0.9 & 0.75 & 87.28  & 11.72 & 45.56  & 13.05 & 6.15 & 6.75\\
Pitch & 3.0 & 0.9 & 0.75 & 87.28  & 11.72 & 45.56  & 13.05 & 6.15 & 6.75\\
Heave & 4.0 & 0.9 & 1.00 & 275.84 & 20.84 & 256.00 & 23.20 & 8.20 & 16.00\\
\bottomrule
\end{tabular}
\end{table}

Solving the algebraic Riccati equation for \eqref{eq:augment} and \eqref{eq:cost} gives $\Kmat_a=\bm{R}^{-1}\Bmat_a^\top\bm{P}=[\Kmat_x\ \ {-\Kmat_i}]$. These gains coincide with the pole-placement construction $\Kmat_x=\W^{-1}\mathrm{blkdiag}([k_p\ k_d])$, $\Kmat_i=\W^{-1}\mathrm{diag}(k_i)$ to relative differences of $3\times10^{-14}$ and $5\times10^{-14}$, and the closed-loop eigenvalues are $-2.70\pm1.31\mathrm{j}$ (roll and pitch), $-3.60\pm1.74\mathrm{j}$ (heave), $-0.75$ (twice) and $-1.00$, exactly on the specification (Fig.~\ref{fig:poles}). By contrast, the earlier design bisected a scalar $\rho$ in $\bm{R}=\rho\bm{I}$ until the slowest pole met a bandwidth target; with integral augmentation the slow poles converge to transmission zeros fixed by the ratio $\bm{Q}_i/\bm{Q}$, which $\rho$ does not affect, so the search ran to its lower bracket $\rho=10^{-9}$ and returned gains of order $6\times10^8$.

\begin{figure}[H]
\centering

\caption{Closed-loop eigenvalues. All lie on the $\zeta=0.9$ rays or on the real axis, well to the left of the wave peak frequency.}
\label{fig:poles}
\end{figure}

\subsection{State estimation}
Only $\alpha$, $\theta$ and $z$ are measured, so the rates in \eqref{eq:law} are reconstructed by a discrete KF \cite{kalman1960} designed on the ZOH discretization of \eqref{eq:ss} at $T_s=10\un{ms}$,
\begin{equation}
\hat{\xv}_{k|k}=\hat{\xv}_{k|k-1}+\bm{L}_k\left(\bm{y}_k-\Cmat\hat{\xv}_{k|k-1}\right),
\label{eq:kf}
\end{equation}
with the measurement covariance set from the sensor noise of Section~\ref{sec:system} and the process covariance representing the unmodeled wave forcing. The measurement covariance must reflect the physical sensor noise: an overestimated value makes the filter ignore the measurements and trust the model, which is the failure observed with the earlier estimator \cite{perez2025stage2}. \todo{final estimator form (KF or EKF), covariances, steady-state gain, and estimation error versus the ideal sensor in the digital twin.}

\subsection{Discrete implementation}
The controller is discretized at $T_s=10\un{ms}$, the integral states are updated by forward Euler with an anti-windup gain $\beta_{aw}=1$, and the command is saturated at the cylinder force limit. The design is applied to the digital twin by changing four block parameters, without structural edits: the feedback gain becomes $\Kmat_x\bm{S}$, which absorbs both the state feedback and the $\W^{-1}$ allocation; the former allocation gain $\bm{T}^{-1}$ becomes the identity; the feedforward becomes $\Fv_\mathrm{trim}$ instead of about $64\un{N}$ per actuator; and the reference sets the commanded height. Fig.~\ref{fig:arch} shows the complete loop. \todo{confirm discretization of the integrator.}

\begin{figure}[H]
\centering

\caption{Closed-loop architecture. The feedforward $\Fv_\mathrm{trim}$ cancels gravity, $\Kmat_x$ and $\Kmat_i$ include the allocation $\W^{-1}$, and the KF reconstructs the rates from the sampled measurements.}
\label{fig:arch}
\end{figure}

% ==================================================================
\section{Processor-in-the-Loop implementation}
\label{sec:pil}
% ------------------------------------------------------------------
% RESERVED SECTION. Budget: about 1.5 pages including Figs. 10-11 and Table 6.
% ------------------------------------------------------------------

\subsection{Setup}
In the PiL configuration the discretized controller and estimator run on an embedded microcontroller, while the digital twin, including waves and sensor models, runs on the host computer. The two exchange the sampled measurements and the actuator commands every $T_s$ through a serial link (Fig.~\ref{fig:pilsetup}). \todo{target board, clock, toolchain (Embedded Coder or support package), communication protocol and baud rate, synchronization with the host.}

\begin{figure}[H]
\centering

\caption{PiL configuration: host computer running the digital twin and microcontroller executing the control law and estimator.}
\label{fig:pilsetup}
\end{figure}

\subsection{Execution metrics}
\todo{describe the code generation flow and report the metrics of Table~\ref{tab:pil}.}

\begin{table}[H]
\centering
\caption{PiL execution metrics.}
\label{tab:pil}
\footnotesize
\begin{tabularx}{\columnwidth}{@{}Xl@{}}
\toprule
Metric & Value\\
\midrule
Target microcontroller and clock & \todo{}\\
Sampling period $T_s$ & $10$ ms\\
Average / worst-case execution time & \todo{}\\
CPU load at $T_s$ & \todo{}\\
Flash / RAM usage & \todo{}\\
Max.\ SiL--PiL output difference & \todo{}\\
\bottomrule
\end{tabularx}
\end{table}

\subsection{SiL versus PiL}
\todo{compare the SiL and PiL responses of roll, pitch and heave under the same wave realization (Fig.~\ref{fig:pilsil}) and discuss numerical precision and timing effects.}

\begin{figure}[H]
\centering

\caption{Roll, pitch and heave under P--M waves with the controller executed in SiL and in PiL.}
\label{fig:pilsil}
\end{figure}

% ==================================================================
\section{Results and discussion}
\label{sec:results}

\subsection{Disturbance rejection}
For each decoupled axis the loop transfer is $L(s)=(k_ds^2+k_ps+k_i)/s^3$, so the output sensitivity is
\begin{equation}
S(s)=\frac{1}{1+L(s)}=\frac{s^3}{s^3+k_ds^2+k_ps+k_i}.
\label{eq:sens}
\end{equation}
Its triple zero at the origin gives $60\un{dB/decade}$ of attenuation at low frequency, which is the structural reason why an integral-augmented double integrator rejects slow wave motion so effectively. Fig.~\ref{fig:sens} and Table~\ref{tab:atten} compare the proposed and previous designs at the wave peak: the attenuation improves by factors of $19$ and $40$. This improvement is not the result of finer tuning but of placing the bandwidth deliberately, which in turn requires a correct plant model.

\begin{figure}[H]
\centering

\caption{Output sensitivity of the proposed design ($\omega_n=3$ rad/s for roll and pitch, $4$ rad/s for heave) and of the previous design ($\omega_n\approx0.65$ rad/s), with the P--M spectrum shown for reference.}
\label{fig:sens}
\end{figure}

\begin{table}[H]
\centering
\caption{Attenuation at the wave spectral peak $\omega_p=0.628$ rad/s.}
\label{tab:atten}
\footnotesize
\begin{tabular}{@{}lccc@{}}
\toprule
Design & $|S(j\omega_p)|$ & dB & Improvement\\
\midrule
Previous, $\omega_n\approx0.65$ rad/s & $0.520$ & $-5.7$ & baseline\\
Roll/pitch, $\omega_n=3$ rad/s & $0.027$ & $-31.2$ & $19\times$\\
Heave, $\omega_n=4$ rad/s & $0.013$ & $-37.8$ & $40\times$\\
\bottomrule
\end{tabular}
\end{table}

\subsection{Reference tracking and actuator authority}
The loop is designed as a regulator, whose main task is disturbance rejection; reference tracking is a secondary property. With a direct reference, the numerator zero introduced by the integral action at $s=-k_i/k_p$ ($-0.517\un{rad/s}$ for roll and pitch, $-0.690\un{rad/s}$ for heave) produces a $19.9\%$ overshoot with $2\%$ settling times of $4.8\un{s}$ and $3.6\un{s}$ (Fig.~\ref{fig:step}a). A first-order prefilter that cancels this zero,
\begin{equation}
r_f(s)=\frac{k_i/k_p}{s+k_i/k_p}\,r(s),
\label{eq:prefilter}
\end{equation}
yields a monotone response settling in $5.9\un{s}$ and $4.4\un{s}$, dominated by the integrator pole. Either choice suits a constant height reference; the prefilter is preferred if the reference is slewed. For a $1^\circ$ roll step the actuator forces deviate by about $13\un{N}$ on legs 1 and 3 and $27\un{N}$ on leg 2 from a static trim of $251$--$289\un{N}$ (Fig.~\ref{fig:step}b), i.e. about $10\%$ of the trim for a $1^\circ$ error, the right order of magnitude for this machine, whereas the previous design demanded of order $10^8\un{N/rad}$. Over an envelope of $2^\circ$ tilt, $10^\circ/\mathrm{s}$ tilt rate, $8\un{cm}$ heave and $0.4\un{m/s}$ heave rate, the commanded forces remain within $[-136,669]\un{N}$, well inside the $\pm3\un{kN}$ capability of the cylinder.

\begin{figure}[H]
\centering

\caption{(a) Closed-loop step responses with direct reference (solid) and with prefilter (dashed). (b) Actuator forces during a $1^\circ$ roll reference step.}
\label{fig:step}
\end{figure}

\subsection{Closed-loop digital twin under waves}
\todo{report the digital twin response under the P--M sea state (Fig.~\ref{fig:dtwaves}): RMS and peak roll, pitch and heave errors with and without control, settling from the initial condition, actuator forces and stroke usage, and drift of the free yaw.}

\begin{figure*}[t]
\centering

\caption{Closed-loop digital twin under P--M waves: roll, pitch, heave and actuator forces, with the uncontrolled base motion shown for reference.}
\label{fig:dtwaves}
\end{figure*}

\subsection{Comparison with previous approaches}
Table~\ref{tab:compare} compares the three control stages of MARLUP. Replacing the three decentralized PID loops by a single state-feedback law reduced the simulation cost of $10\un{s}$ of response from $5$--$13\un{h}$ to about $1$--$2\un{min}$ \cite{perez2025stage2}, and the identified model is what turns that computational gain into a stable and well-damped closed loop.

\begin{table}[H]
\centering
\caption{Comparison of the MARLUP control stages.}
\label{tab:compare}
\footnotesize
\begin{tabularx}{\columnwidth}{@{}>{\raggedright\arraybackslash}p{1.45cm}LLL@{}}
\toprule
 & PID \cite{gonzalez2025} & LQR+KF \cite{perez2025stage2} & This work\\
\midrule
Plant model & none (tuned on twin) & analytic, simplified & identified from twin\\
Waves & sinusoidal & P--M & P--M\\
Sensors & ideal & noisy, quantized & noisy, quantized\\
$|S(j\omega_p)|$ & \todo{} & $-5.7$ dB & $-31$ to $-38$ dB\\
Result on twin & stable, gains up to $10^{15}$ & marginal, ${\approx}20$ s & \todo{}\\
Sim.\ time (10 s) & $5$--$13$ h & $1$--$2$ min & \todo{}\\
\bottomrule
\end{tabularx}
\end{table}

\subsection{Limitations}
The model is exact only at $\qv_0$; repeating the identification at other heights would convert its validity range from an estimate into a measured bound. The actuators are ideal force sources, so hydraulic dynamics, friction and bandwidth limits are not represented, which is the main reason for keeping the closed loop at $3$--$4\un{rad/s}$ rather than faster. The double-integrator structure of $\Amat$ is asserted rather than identified, the Euler angles coincide with body roll and pitch only near level, and the unactuated yaw of the base joint may drift in long simulations and rotate the actuator frame away from the measurement frame. Lift-off loads are not yet included. \todo{add any limitation revealed by the PiL runs.}

% ==================================================================
\section{Conclusions}
\label{sec:concl}
An actively stabilized floating launch platform for small rockets was developed at the level of a validated digital twin and embedded controller. The analysis showed that the free-platform rigid-body simplification misrepresents a closed-chain mechanism with heavy legs by $71\%$, and that the map from actuator forces to accelerations can instead be identified exactly at the operating point from four short simulations, without modifying the plant and with an independent prediction as validation. On the identified model, an integral LQR with closed-form weights places the bandwidth five to six times above the wave spectral peak and attenuates the dominant wave motion by $31$ to $38$ dB, with actuator demands of the correct order of magnitude, and was executed in PiL together with the state estimator. \todo{summarize the PiL and digital-twin wave results.} Future work comprises the modeling of the hydraulic actuators, gain scheduling over the stroke, the inclusion of lift-off loads and hardware-in-the-loop tests leading to a scaled prototype at sea.

\section*{Acknowledgements}
The authors thank TECSpace and the School of Electronics Engineering of the Instituto Tecnol\'ogico de Costa Rica for supporting the MARLUP project, and the members of earlier MARLUP stages whose work is referenced here. \todo{complete acknowledgements and funding.}

\bibliography{biblio}

\end{document}

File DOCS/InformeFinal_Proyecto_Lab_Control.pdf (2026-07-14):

GONZALEZ, GUERRERO SISTEMA DE CONTROL ACTIVO PARA LA ESTABILIZACI ´ | ON DE LA PLATAFORMA MARLUP | 1 ´

# Sistema de Control Activo para la Estabilizacion de ´ la Plataforma MARLUP

Hillary Gonzalez Gonz ´ | alez y Kendall Guerrero Gonz ´ | alez Escuela de Ingenier ´ | ía Electronica, Instituto Tecnol ´ | ogico ´

de Costa Rica (ITCR), 30101 Cartago, Costa Rica, {Hillagonzalez, kendall.guerrero}@estudiantec.cr

Resumen—El objetivo de este proyecto es disenar e imple- ˜ mentar un sistema de control activo que ayude a estabilizar una plataforma marina utilizada para el lanzamiento de cohetes. El trabajo se dividira en dos etapas principales. En la primera, se ´
modelara el sistema aplicando principios de control autom ´ | atico ´
mediante el uso del software MATLAB, específicamente en el entorno de simulacion Simscape Multibody, posteriormente, se ´
realizaran simulaciones para analizar c ´ | omo responde la plata- ´
forma ante perturbaciones. Debido al alcance del proyecto, no
se contempla la construccion de un prototipo f ´ | ísico; el analisis ´
se limitara a resultados obtenidos mediante simulaci ´ | on. ´

Palabras Clave—Control, PID, Controlador, planta, entradas, salidas, sensores y actuadores.

I. INTRODUCCION´

El proyecto MARLUP consiste en la creacion de una ´ plataforma marina de lanzamiento de cohetes con motores de clase A hasta clase H, actualmente en el area de control se ´ necesita desarrollar un sistema de amortiguamiento controlado para asegurar la estabilidad de la plataforma, en la figura 1 se puede observar el prototipo deseado de la plataforma marina.

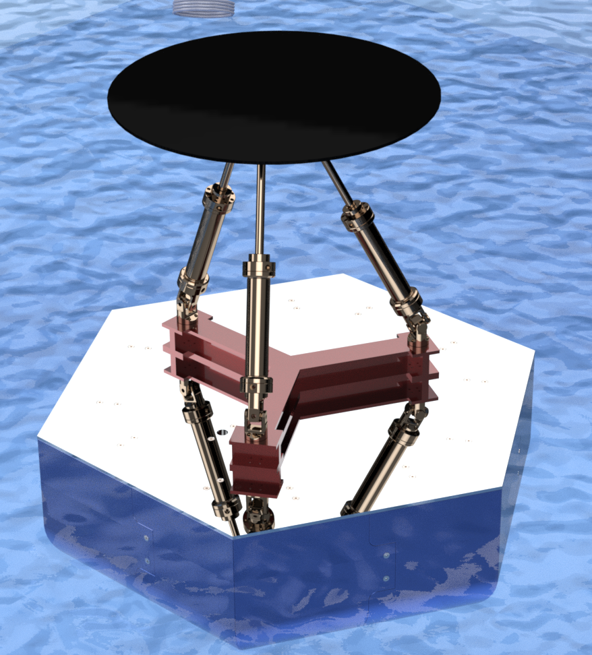
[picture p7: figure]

Figura 1. Modelo CAD de Plataforma Flotante con Sistema de Estabilizacion´

El sistema que se propone realizar para la estabilizacion de ´ la lanzadera es similar a un hexapodo o plataforma Stewart, el ´ cual es un dispositivo de movimiento que puede posicionar un objeto en seis grados de libertad: tres movimientos lineales (a lo largo de los ejes X, Y y Z) y tres rotacionales (alrededor de
los ejes de guinada, cabeceo e inclinaci ˜ | on) como se observa ´

en la figura 2 [1] [2]. Este sistema permite la estabilizacion de ´ la lanzadera de cohetes, mediante los 6 actuadores que serían controlados por las senales recibidas de sensores IMU. ˜

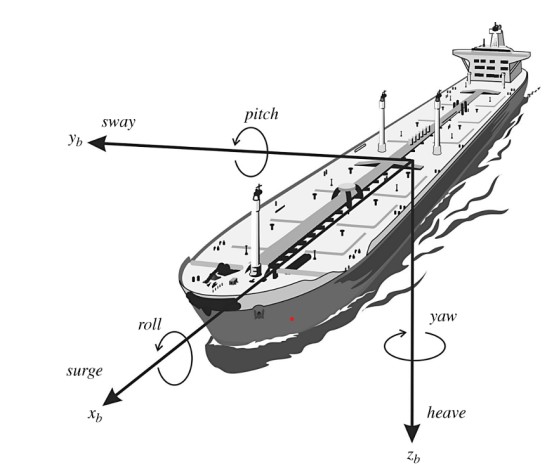
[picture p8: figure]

Figura 2. Esquema de los seis grados de libertad considerados en la estabilizacion de la lanzadera [3]. ´

Para efectos del proyecto, se desarrollara un modelo de ´
simulacion que represente el comportamiento din ´ | amico de una ´
plataforma marina utilizada para el lanzamiento de cohetes. A diferencia del enfoque inicial, que consideraba un sistema con
un unico grado de libertad y con control de ´ | unicamente una ´
variable, se opta por un modelo mas completo que contemple ´ el movimiento de la plataforma en tres ejes del espacio, permitiendo capturar de forma mas realista las perturbaciones ´ ocasionadas por el entorno marino y la reaccion de la plata- ´ forma en todo momento. En el cuadro I se puede observar
de forma mas detallada la descripci ´ | on de cada movimiento ´
asociada a su eje respectivo.

Cuadro I
GRADOS DE LIBERTAD Y MOVIMIENTOS ASOCIADOS [3]
Descripcion´ | Ingles´ | Espanol ˜ | Tipo (uds.)
Mov. vertical Mov. lateral Mov. longitudinal Rot. alrededor zb Rot. alrededor xb Rot. alrededor yb | Heave Sway Surge Yaw Roll Pitch | Arfada Deriva Largada Guinada ˜ Balanceo Cabeceo | Trasl. [m/s] Trasl. [m/s] Trasl. [m/s] Rotac. [rad/s] Rotac. [rad/s] Rotac. [rad/s]

Tomando esto en cuenta, los movimientos considerados para la aplicacion del control son los siguientes: ´

GONZALEZ, GUERRERO SISTEMA DE CONTROL ACTIVO PARA LA ESTABILIZACI ´ | ON DE LA PLATAFORMA MARLUP | 2 ´

Movimiento vertical en el eje z: Arfada
Rotacion alrededor de ´ | xb: Balanceo
Rotacion alrededor de ´ | yb: Cabeceo
El sistema sera modelado como un sistema de m ´ | ultiples ´
entradas y multiples salidas (MIMO), lo que permitir ´ | a analizar ´
el comportamiento dinamico en traslaciones y rotaciones alre- ´ dedor de los ejes principales anteriormente mencionados. Este modelo sera implementado y evaluado mediante simulaciones ´ computacionales, sin llegar a la construccion de un prototipo ´ físico.
A continuacion, en la figura 3 se puede observar el diagrama ´ de bloques del sistema de control de la plataforma marina considerando multiples grados de libertad. ´

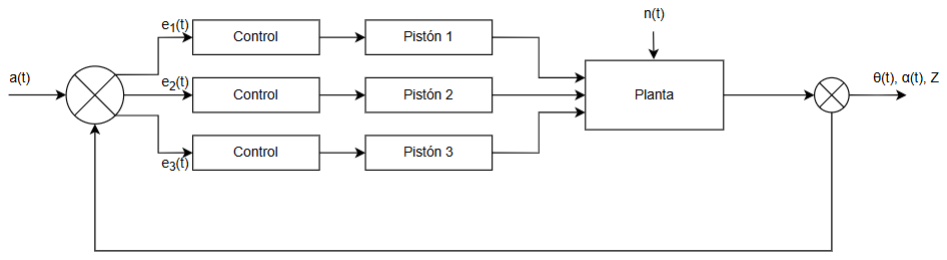
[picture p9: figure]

Figura 3. Diagrama de bloques de la plataforma marina

Seguidamente, se describen las partes del sistema con mayor detalle:
Referencia a(t): Angulo de inclinaci ´ | on deseado de la ´
plataforma.
Error e(t): Diferencia entre la referencia a(t) y la salida real θ(t), α(t) y desplazamiento Z .
Control: Senal del control en funci ˜ | on del error a corregir. ´
Actuador: Dispositivo que permita elevar o bajar el
angulo de la plataforma seg ´ | un sea necesario para su es- ´
tabilizacion, debido al movimiento de las olas y posibles ´ perturbaciones que la desequilibran.
Planta: Modelo dinamico de la plataforma. ´ Perturbaciones n(t): Representa la fuerza externa que afecta el sistema, en este caso, el oleaje.
Sensor: Sensor que identifique el punto de equilibrio, mida y brinde la informacion de las coordenadas por ´ corregir.
Salidas: angulos ´ | θ(t), α(t) y desplazamiento Z: Las
variables por controlar, para este contexto son los angu- ´ los de la plataforma con respecto a la horizontal y el desplazamiento en un eje.

II. OBJETIVO GENERAL
1. Disenar y simular un sistema de control activo para la ˜ estabilizacion tridimensional de una plataforma marina ´ destinada al lanzamiento de cohetes, mediante el modelado en Simscape Multibody para obtener la planta del sistema y evaluar su comportamiento dinamico ante ´ perturbaciones marinas.

III. OBJETIVOS ESPECÍFICOS

1. Modelar la plataforma marina en el entorno de Simscape Multibody, considerando las restricciones de movimiento y los elementos de sujecion del sistema. ´
2. Disenar un sistema de control activo que permita man- ˜ tener la estabilidad de la plataforma ante perturbaciones como el oleaje.
3. Simular el comportamiento de la plataforma de lanzamiento controlada, en busca de una respuesta eficiente ante las posibles perturbaciones que afecten el punto de equilibrio del sistema.

IV. MODELADO DE PLANTA Y CONTROLADOR
La estabilidad de una plataforma marina es uno de los desafíos claves que existe en los sistemas flotantes sujetos a perturbaciones externas como el oleaje. Para poder disenar un ˜ controlador efectivo, es necesario modelar la dinamica de la ´ planta. A continuacion se presenta el modelo de la planta y una ´ estrategia de control adecuada que se utilizara para demostrar ´ la capacidad de controlar el sistema.
V. MODELADO DE LA PLANTA

V-A. Descripcion F ´ ísica del Sistema
El sistema considerado es una plataforma flotante, como se observa en la figura 4 con tres grados de libertad, dos rotacioneles (Pitch, and Roll) y uno transaccional (z).

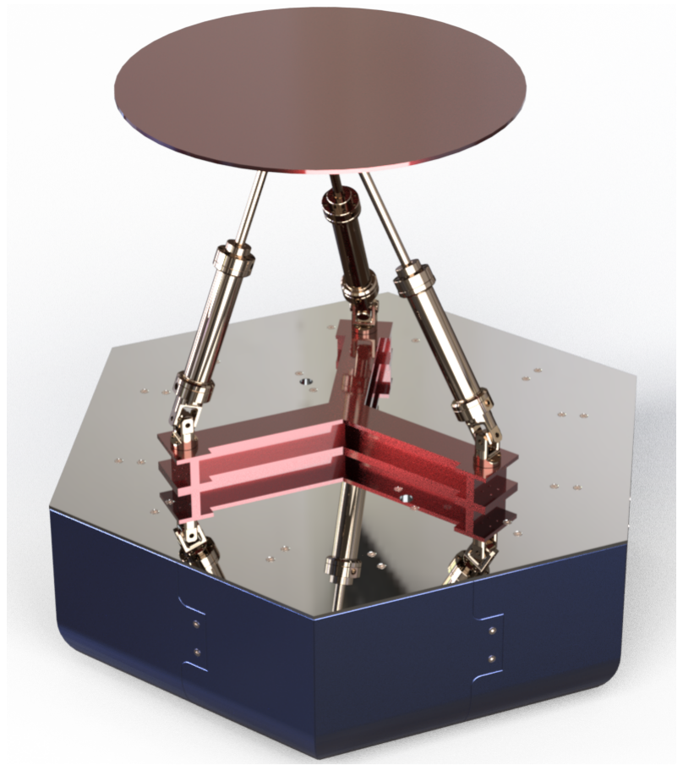
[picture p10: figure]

Figura 4. Diagrama general de la plataforma

Para esto se toman en cuenta las siguientes consideraciones: La base flotante del sistema puede ser considerada como un objeto semisumergible que se nos proporciona previamente disenada por el grupo de estructuras de MARLUP. Esta estruc- ˜ tura sirve como el soporte principal del sistema y disminuye las perturbaciones del oleaje, que corregira el sistema de ´ control.
La plataforma de control modelada esta compuesta por un soporte donde se instalan los 3 actuadores (pistones). Estos pistones estan conectados a un triangulo el cual soportan la ´ base superior, que se desea controlar, de tal manera que la base circular permanezca totalmente horizontal y a una altura asignada, tanto las uniones inferiores del piston como las ´ superiores estan conectados por medio de juntas universales ´ tal como se observa en la figura 5.

GONZALEZ, GUERRERO SISTEMA DE CONTROL ACTIVO PARA LA ESTABILIZACI ´ | ON DE LA PLATAFORMA MARLUP | 3 ´

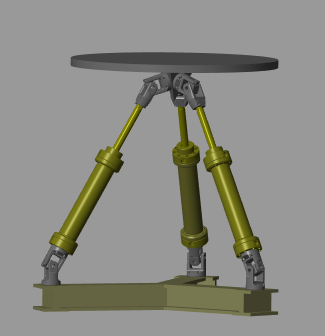
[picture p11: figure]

Figura 5. Montaje del sistema a controlar

El actuador es el componente encargado de generar el movimiento compensador en la base superior, donde ajusta su posicion en respuesta a las perturbaciones externas como ´ el oleaje. Para modelar la planta, se realiza el montaje en el sofware Simscape Multibody de MATLAB donde se le asignan todos los movimientos físicos permitidos así como sus debidas restricciones (Ver Figura 15, 16, 17). Dado que la base flotante
ya esta dise ´ | nada y proporcionada, su movimiento se modelar ˜ | á
como una perturbacion externa y no como parte activa de la ´ funcion de transferencia de la planta, como se observa en la ´ figura 5.

Debido al peso de la plataforma, la masa de los flotadores y su geometría, las perturbaciones generadas por las olas no se transmitiran en completa amplitud y frecuencia hasta la parte ´
superior del sistema, en su lugar, estas sufriran una atenuaci ´ | on´
natural debido a la distribucion de la masa y la estructura de la ´ plataforma en sí. El oleaje se considerara m´ as adelante como ´ perturbaciones externas al sistema.

VI. CONTROLADOR

Para lograr la estabilizacion de la plataforma en los tres ´ grados de libertad seleccionados (cabeceo, balanceo y desplazamiento vertical), se implementan controladores PID individuales en cada piston, cada uno responde a un movimiento. El ´
diseno de estos controladores se realiza despues del an ˜ | alisis de ´
la respuesta libre del sistema ante perturbaciones simuladas, como se muestra en las Figuras 6, 7, y 8, correspondientes respectivamente a los movimientos de Pitch, Roll y Z.

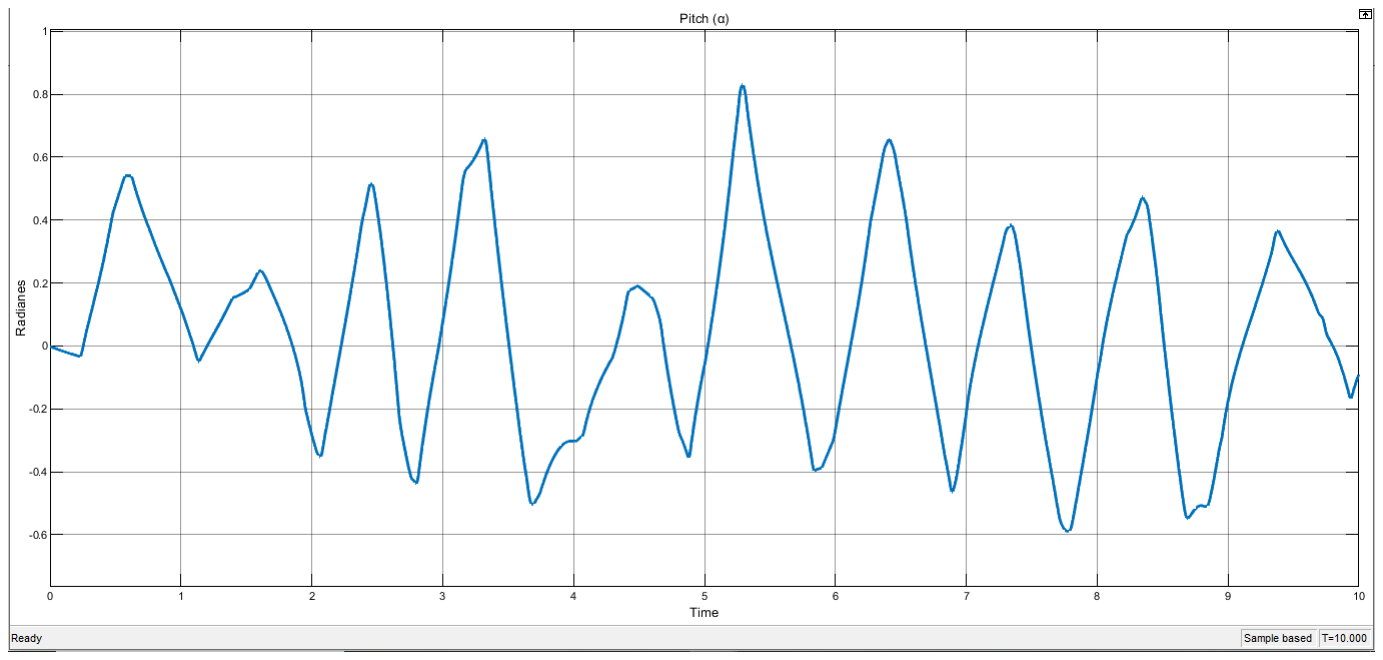
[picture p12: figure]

Figura 6. Rotacion Pitch que se desea controlar. ´

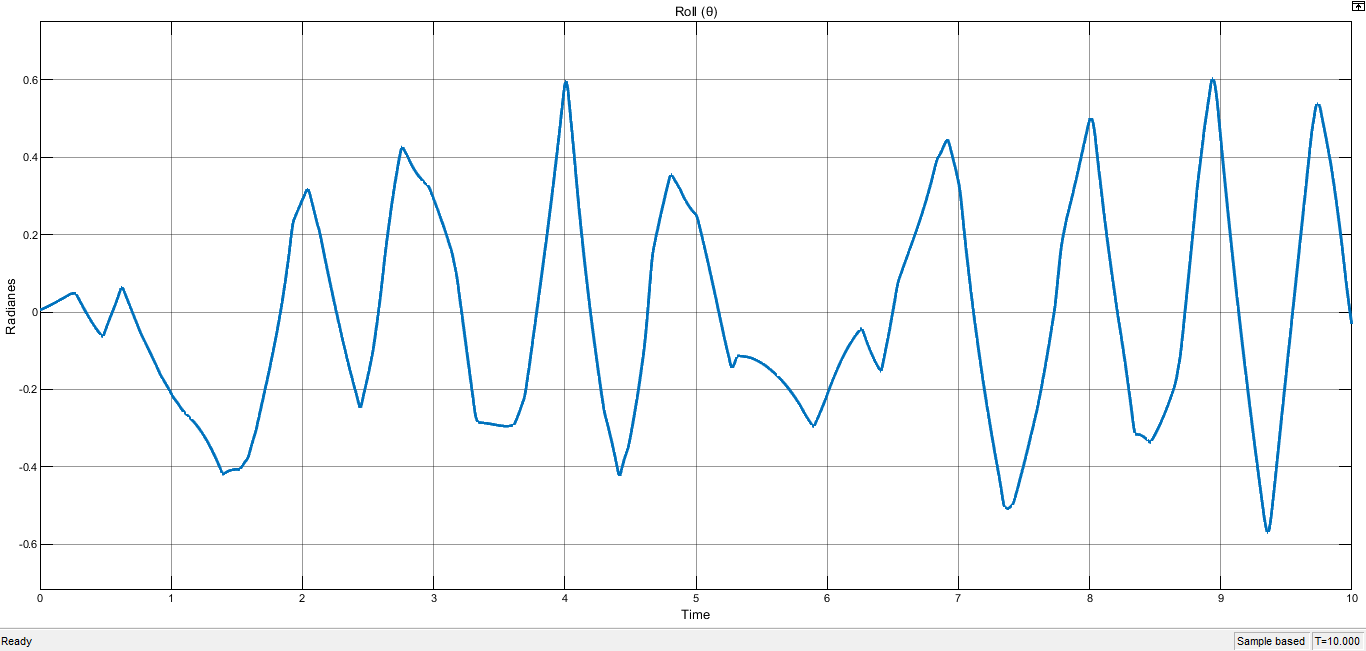
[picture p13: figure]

Figura 7. Rotacion Roll que se desea controlar. ´

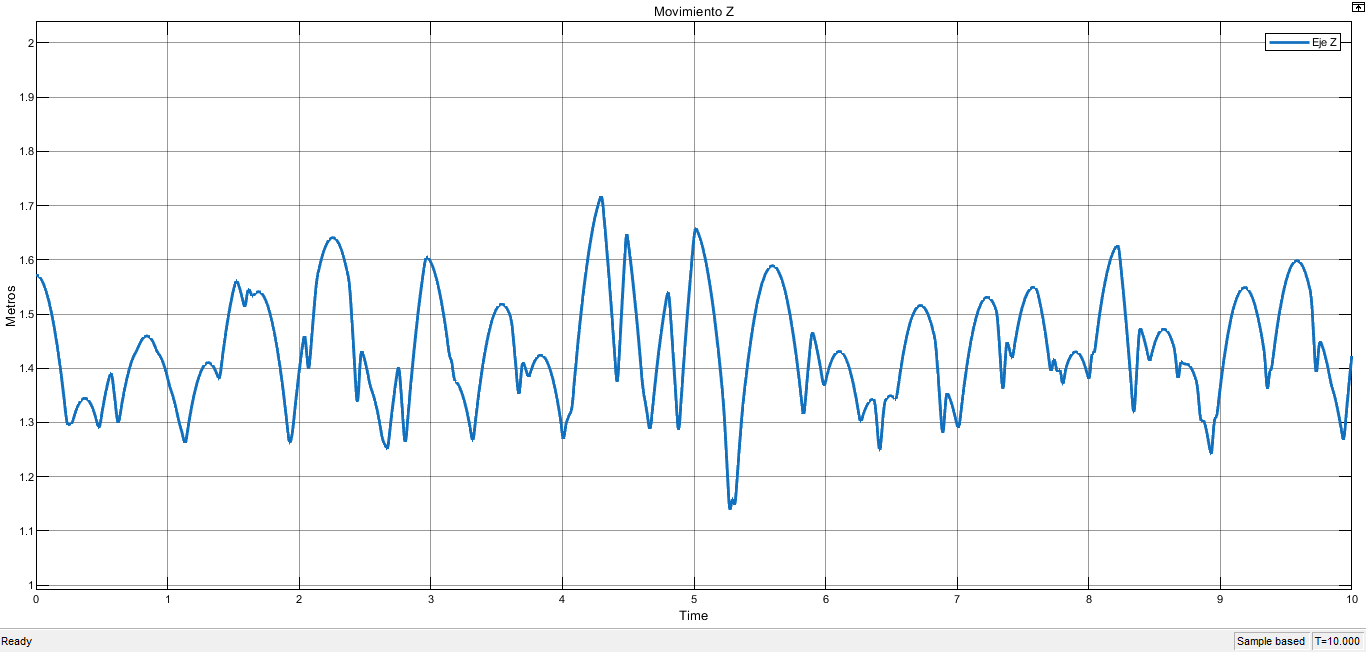
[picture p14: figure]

Figura 8. Despedazamiento Z que se desea Controlar.

El proceso de diseno se llev ˜ | o a cabo utilizando la herramien- ´
ta PID Tuner del software MATLAB, la cual permite ajustar los parametros del controlador para lograr un comportamiento ´ adecuado entre estabilidad, tiempo de asentamiento y sobreimpulso. En las Figuras 9 y 10 se presentan los resultados
del diseno para los movimientos de rotaci ˜ | on (Roll y Pitch), la ´
misma metodología se aplica para obtener el controlador del desplazamiento vertical (movimiento Z), aunque por razones
de iteracion en el software su gr ´ | afico no se incluye en este ´
apartado, pero sí sus valores de constantes, junto con las del diseno Roll y Pitch, los cuales se pueden ver en la Cuadro II. ˜ Dado que el sistema completo involucra multiples contro- ´ ladores operando de manera simultanea, fue necesario in- ´ troducir ciertas tolerancias en cuanto a las especificaciones
de desempeno, se consider ˜ | o adecuado permitir sobreimpulsos ´
moderados y tiempos de estabilizacion m ´ | as amplios, con el ´

GONZALEZ, GUERRERO SISTEMA DE CONTROL ACTIVO PARA LA ESTABILIZACI ´ | ON DE LA PLATAFORMA MARLUP | 4 ´

objetivo de garantizar una simulacion computacional eficiente ´
y estable, se establece como criterio una cota inferior de 0,1
segundos para el tiempo de estabilizacion, y se dise ´ | naron ˜
los controladores de forma que se acercaran a este valor sin comprometer la robustez del sistema.

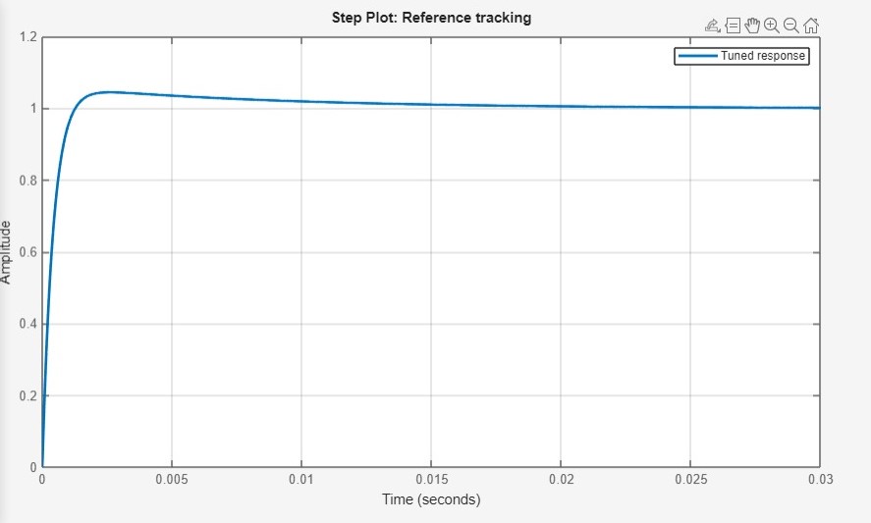
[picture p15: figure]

Figura 9. Diseno de controlador PID para Rotaci ˜ | on Roll. ´

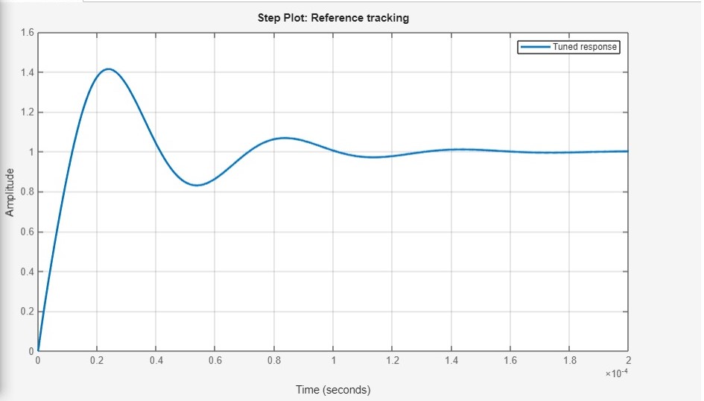
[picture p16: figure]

Figura 10. Diseno de controlador PID para Rotaci ˜ | on Pitch. ´

Cuadro II
CONSTANTES DE LOS CONTROLADORES PID POR EJE DE MOVIMIENTO
Movimiento | Kp | Ki | Kd
Pitch (α) | -110793333 | -1989642710 | -836020
Roll (θ) | -1900205250702 | -1354372383261765 | -592357524
Z | 112080280328 | 148230620513690 | 18829615

Una vez aplicados los controladores, se evaluo nuevamente ´ el comportamiento de la plataforma, observandose una notable ´ mejora en la estabilidad y reduccion de las oscilaciones no ´ deseadas. Las Figuras 11, 12 y 13 muestran las respuestas controladas de los movimientos de Pitch, Roll y Z respectivamente, evidenciando el correcto funcionamiento del sistema de control activo implementado.

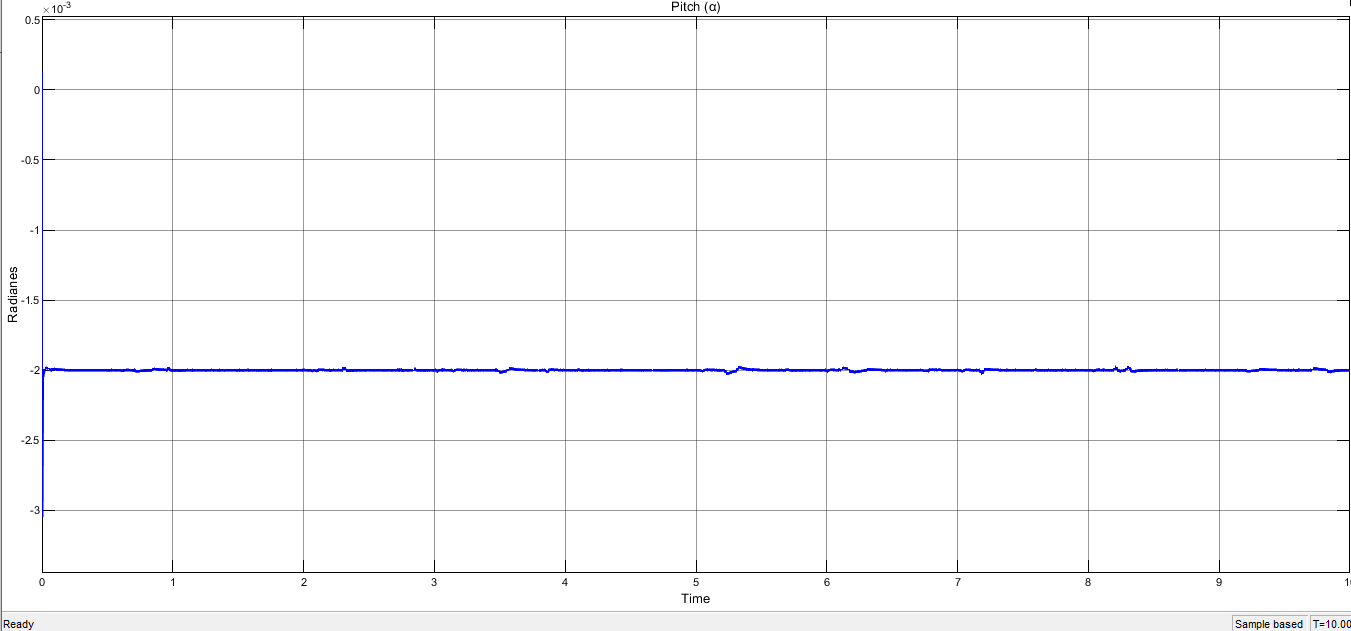
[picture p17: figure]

Figura 11. | Rotacion Pitch despu ´ | es de aplicar el controlador, 5 horas de ´
simulacion´

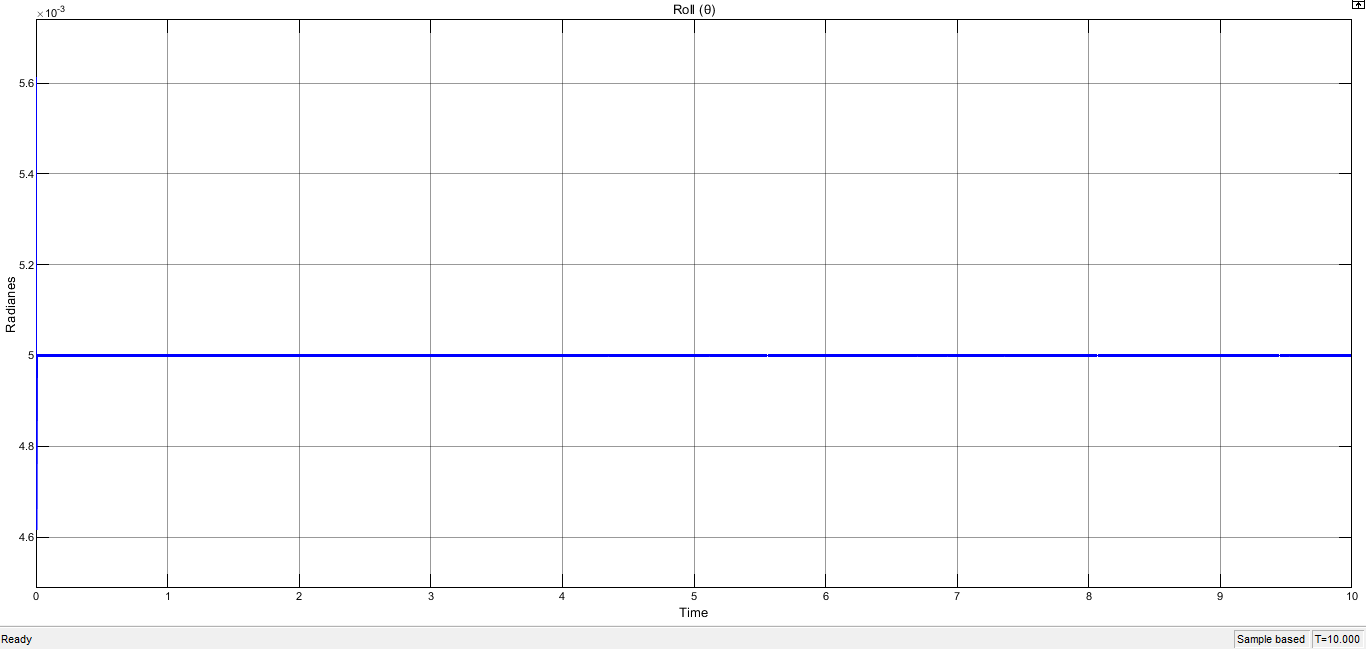
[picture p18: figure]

Figura 12. | Rotacion Roll despu ´ | es de aplicar el controlador, 5 horas de ´
simulacion´

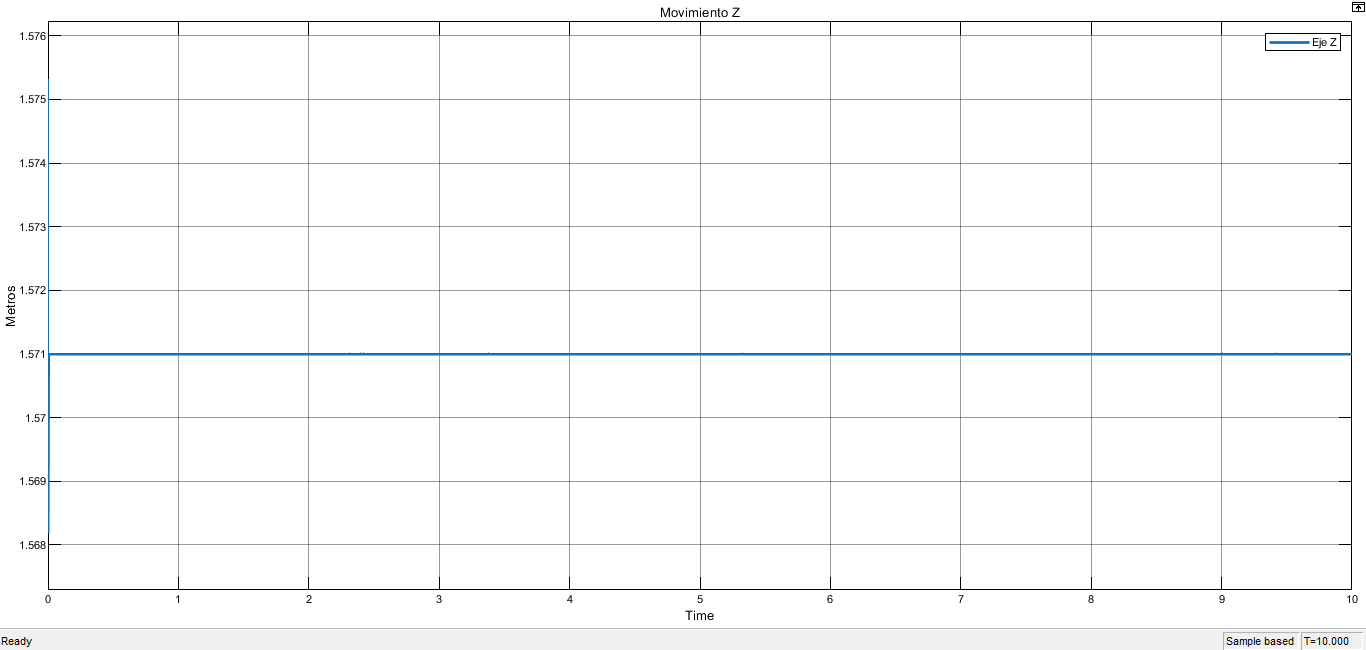
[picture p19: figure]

Figura 13. Movimiento Z despues de aplicar el controlador, 5 horas de ´ simulacion´

VII. SIMULACION´

VII-A. Modelado de la perturbacion del sistema ´

Para llevar a cabo la simulacion del sistema en estudio, es ´ necesario previamente modelar el comportamiento del mar. En este caso, se considero un oleaje regular, el cual se ´
represento mediante dos se ´ | nales senoidales. La amplitud de ˜
estas senales se fij ˜ | o en 0.1 m seg ´ | un la Escala de Douglas ´
[3], ya que no se espera un oleaje fuerte. Esta decision se ´ justifica debido a que, dentro de los requisitos de operacion´ establecidos para la plataforma, se considera que el sistema
se pondra en funcionamiento ´ | unicamente bajo condiciones ´
ideales del entorno marino. Por lo tanto, se asumio una ´

GONZALEZ, GUERRERO SISTEMA DE CONTROL ACTIVO PARA LA ESTABILIZACI ´ | ON DE LA PLATAFORMA MARLUP | 5 ´

perturbacion suave que permite evaluar la estabilidad y el ´
desempeno del sistema bajo un escenario controlado y seguro. ˜
Esta perturbacion se a ´ | nadi ˜ | o directamente a la base de la ´
plataforma a partir de una union universal que permite el ´ movimiento en los ejes X y Y, como se observa en la figura 14,19.

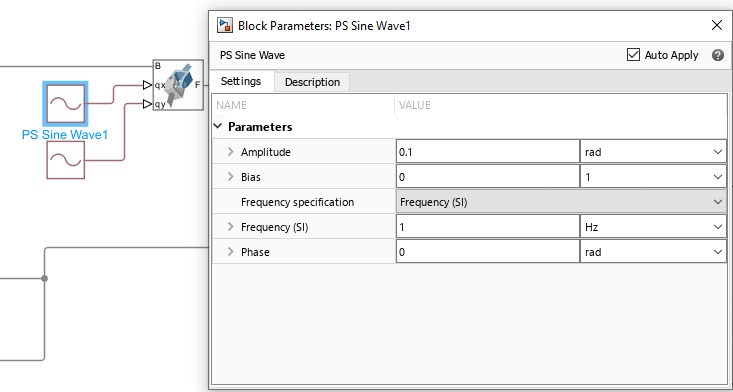
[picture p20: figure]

Figura 14. Implementacion del oleaje en Multibody. ´

VII-B. Consideraciones de simulacion´
Se definio un tiempo de simulaci ´ | on de 10 segundos para ´
mantener la eficiencia computacional y un buen analisis para ´ resultado, este intervalo permite observar el comportamiento completo del sistema, asegurando que las respuestas transitorias y en estado estacionario se desarrollen adecuadamente.
Se utilizo un bloque de ´ | | Simscape Multibody denominado
Transform Sensor como sensor ideal, el cual se conecto entre ´ el centro geometrico de la base inferior y la base superior que ´ se desea controlar (Ver Figura 18). A partir de este sensor
se extrajeron unicamente las variables de inter ´ | es: ´ Pitch, Roll y
desplazamiento en Z, las cuales se emplearon como senales de ˜ retroalimentacion para el sistema de control. Las referencias ´ iniciales consideradas fueron: Pitch igual a −2 × 10⁻³ rad,
Roll igual a 5 × 10⁻³
| | rad, y Z igual a 1.571 m.

VIII. ANALISIS DE RESULTADOS ´

Luego de implementar los controladores PID sintonizados para los tres grados de libertad seleccionados (Pitch, Roll y Z), se evaluo el comportamiento de la plataforma frente a ´ perturbaciones. Las Figuras 11, 12 y 13 muestran la respuesta del sistema controlado durante un intervalo de simulacion de ´ 10 segundos.

VIII-A. Estabilidad del sistema controlado
1. Movimiento de Pitch (α)
Se logro una significativa reducci ´ | on en la amplitud de ´
oscilacion angular, pasando de un rango no controlado ´ de ±0.8 rad a un valor final estabilizado alrededor de
−2 × 10⁻³ | rad. Ademas, el sistema alcanza un estado ´
casi constante tras una pequena variaci ˜ | on inicial, la ´
cual se le puede atribuir al sobreimpulso permitido en el diseno del controlador Pitch (ver Figura 10), las ˜ oscilacione fueron completamente amortiguadas.
2. Movimiento de Roll (θ)
La respuesta al balanceo tambien muestra una esta- ´
bilizacion r ´ | apida y precisa, manteni ´ | endose en torno a ´
5 × 10⁻³ | rad con mínima variacion, no se observan ´

oscilaciones significativas luego de aplicar el controlador como se observa en la figura 12.
3. Desplazamiento en Z
Se observa una línea practicamente constante en torno ´ a 1.571 m, con variaciones insignificantes, el sistema se estabiliza inmediatamente sin sobreimpulso visible (ver Figura 13).

VIII-B. Evaluacion del entorno Simscape Multibody ´
El uso de la herrramienta Simscape Multibody fue vital para el modelado tridimensional y dinamico de la plataforma. Esta ´
permitio simular las interacciones f ´ | ísicas entre los componen-
tes considerando factores como masa, geometría, restricciones de movimiento y el oleaje. Esta metodología de modelado hizo posible analizar la respuesta dinamica de la plataforma ´ ante perturbaciones suaves con mayor realismo que un modelo simplificado.
El modelado del sistema incluyo juntas mec ´ | anicas (uni- ´
versales, rotacionales, prismaticas y de posici ´ | on), estructuras ´
rígidas, acoples mecanicos entre los actuadores y el sistema, y ´
las perturbaciones senoidales. Todo esto brindo una visi ´ | on m ´ | as´
completa del comportamiento de la plataforma, permitiendo así comprobar el diseno de los controladores en un entorno que ˜ resulta representativo ante una posible implementacion real. ´

IX. CONCLUSIONES
El uso del entorno Simscape Multibody de Simulink de-
mostro ser una herramienta ´ | util y confiable para la simulaci ´ | on´
de plantas complejas, al permitir modelar con precision las ´
dinamicas y consideraciones f ´ | ísicas reales del sistema.
La metodología basada en simulacion con Simscape Multi- ´ body y la herramienta PID Tuner de MATLAB resulto efectiva ´
para disenar los par ˜ | ametros de control. A pesar de la alta ´
magnitud de las constantes calculadas, los resultados obtenidos mostraron un comportamiento robusto, con sobreimpulsos mo-
derados y tiempos de estabilizacion lo suficientemente r ´ | apidos ´
para que el controlador actuara y se permitiera una simulacion´ que comprometiera lo menor posible el rendimiento computacional.
El diseno e implementaci ˜ | on de controladores PID para cada ´
grado de libertad (Pitch, Roll y Z) permitio estabilizar efi- ´ cazmente la plataforma marina simulada bajo condiciones de
perturbacion peri ´ | odica, las respuestas controladas evidencian ´
una reduccion dr ´ | astica en las oscilaciones, tanto rotacionales ´
como traslacionales
Es importante mencionar que, aunque se lograron resultados aceptables, la alta demanda de procesamiento del modelo de la plataforma en multibody representa un desafío considerable en la simulacion del sistema. Las simulaciones llegaron a ´ requerir hasta 10 horas para obtener 5 segundos de respuesta,
lo que llevo a conceder ciertos permisos en el dise ´ | no de los ˜
controladores, como aceptar sobreimpulsos moderados.
Por ultimo, la representaci ´ | on del oleaje mediante se ´ | nales ˜
senoidales permitio validar el sistema en condiciones contro- ´ ladas. Aun as ´ í, se reconoce que para escenarios mas complejos ´ se necesitan modelados de perturbaciones mas realistas para ´ evaluar el sistema bajo condiciones mas exigentes. ´

GONZALEZ, GUERRERO SISTEMA DE CONTROL ACTIVO PARA LA ESTABILIZACI ´ | ON DE LA PLATAFORMA MARLUP | 6 ´
X. INCIDENCIAS
Durante el desarrollo del proyecto se presentaron tiempos de
simulacion excesivos, alcanzando hasta 10 horas para obtener ´ 5 segundos de respuesta. Esto obligo a ajustar los tiempos ´
de estabilizacion y ser m ´ | as permisivos en el dise ´ | no de los ˜
controladores, la mejor simulacion obtenida correspondi ´ | o a ´
una duracion de 5 horas para 10 segundos de respuesta ´ simulada.
Durante el modelado inicial de la planta en Simscape Multibody, se utilizaron juntas (joints) inadecuadas que permitían mas grados de libertad de los requeridos por el sistema, lo ´ cual provocaba que la plataforma se desensamblara durante
la simulacion. Esta situaci ´ | on afect ´ | o el comportamiento de ´
los primeros disenos de controladores PID, impidiendo una ˜ estabilizacion adecuada. Fue necesario rehacer varias veces ´ el ensamblaje del sistema, seleccionando cuidadosamente las juntas apropiadas y ajustando los ejes de referencia locales en cada componente individual, de modo que coincidieran correctamente con las restricciones mecanicas definidas. ´

XI. RECOMENDACIONES
Se recomienda considerar la incorporacion de un mayor ´
numero de actuadores (pistones) en el dise ´ | no del sistema, ˜
en caso de que se desee controlar otros grados de libertad adicionales, como el Yaw, el desplazamiento longitudinal y el lateral, para así lograr una estabilizacion completa de la ´ plataforma.
Otra recomendacion importante es incorporar un modelo de ´ motor electrico al actuador, en el entorno de Simulink antes de ´ implementar el controlador en una planta física, con el fin de
simular de manera mas precisa la din ´ | amica real del actuador y ´
validar la respuesta del sistema en condiciones mas cercanas ´ a la operacion final. ´

REFERENCIAS

[1] S. Arruga Cantalapiedra, “Control de posicionamiento de la plataforma hexapod,” Ph.D. dissertation, Universitat Politecnica de Catalunya, 2011. `
[2] D. A. Arias and J. D. G. Giraldo, “Control de una plataforma stewart,” Pereira, Risaralda, 2015, facultad de Tecnologías, Tecnología Mecatroni- ´ ca.
[3] J. M. B. Mallado, “Modelado y control de una plataforma de estabi-
lizacion inercial,” Trabajo Fin de M ´ | aster, Universidad de Sevilla, 2019, ´
master Universitario en Ingenier ´ | ía Aeronautica, Escuela T ´ | ecnica Superior ´
de Ingeniería, Departamento de Ingeniería de Sistemas y Automatica y ´ Departamento de Física Aplicada III.
[4] N. S. Nise, Control Systems Engineering, 6th ed. USA: John Wiley & Sons Inc, 2011.

XII. ANEXOS
Para visualizar una demostracion del sistema en funciona- ´ miento, se puede acceder al siguiente enlace de video: Video, clic aquí. (https://youtu.be/wLJJEAbgG50)

Figura 15. Modelado 3D de un piston en Simulink Multibody ´

Figura 16. Soporte Superior Piston´

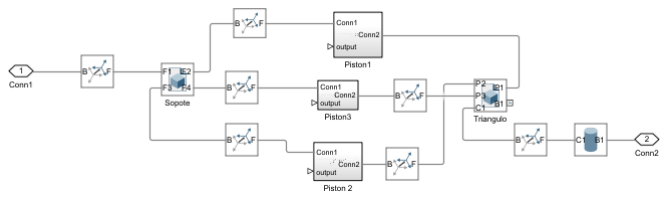
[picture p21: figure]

Figura 17. Modelado 3D de la planta lazo abierto en Simulink Multibody

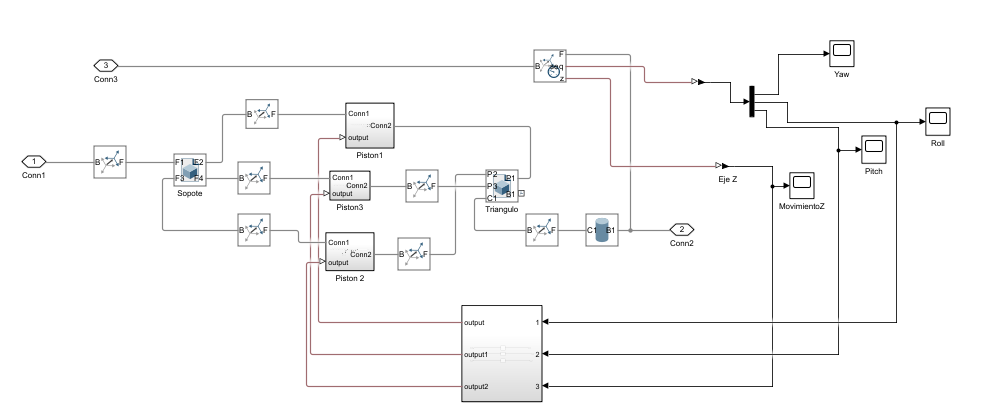
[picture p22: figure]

Figura 18. Modelado 3D del sistema lazo cerrado con controlador aplicado en Simulink Multibody

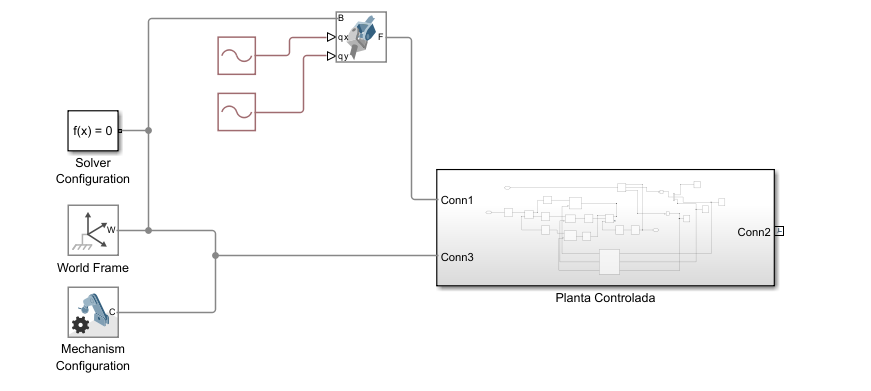
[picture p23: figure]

Figura 19. Modelado 3D completo del sistema con perturbaciones y controlador aplicado en Simulink Multibody

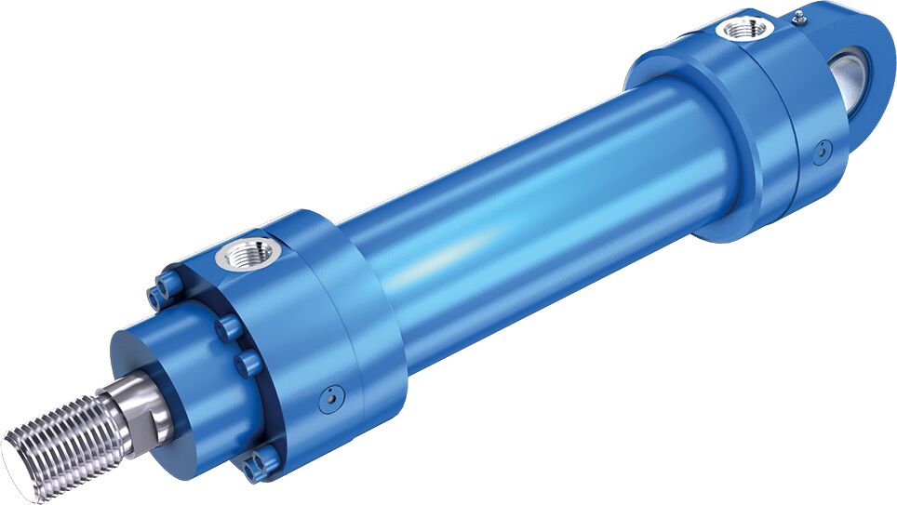
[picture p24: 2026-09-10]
FINAL MODEL/Paper_IAC/Piston.jpg

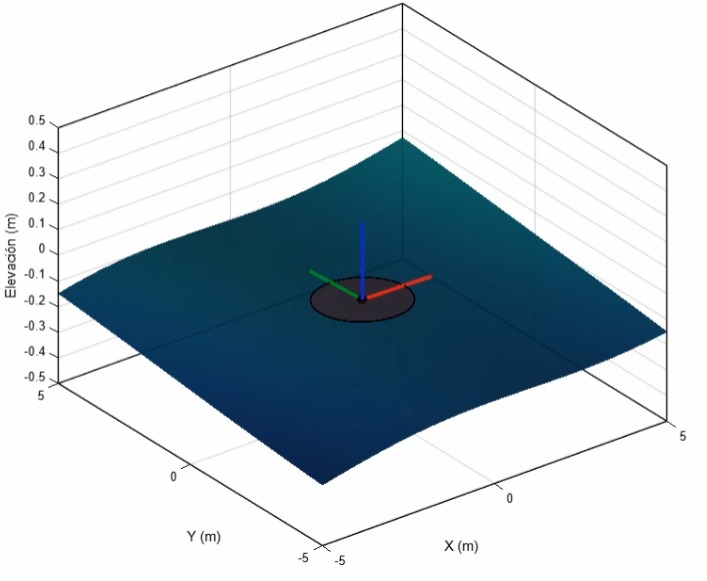
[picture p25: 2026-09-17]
FINAL MODEL/Paper_IAC/Oleaje.jpeg

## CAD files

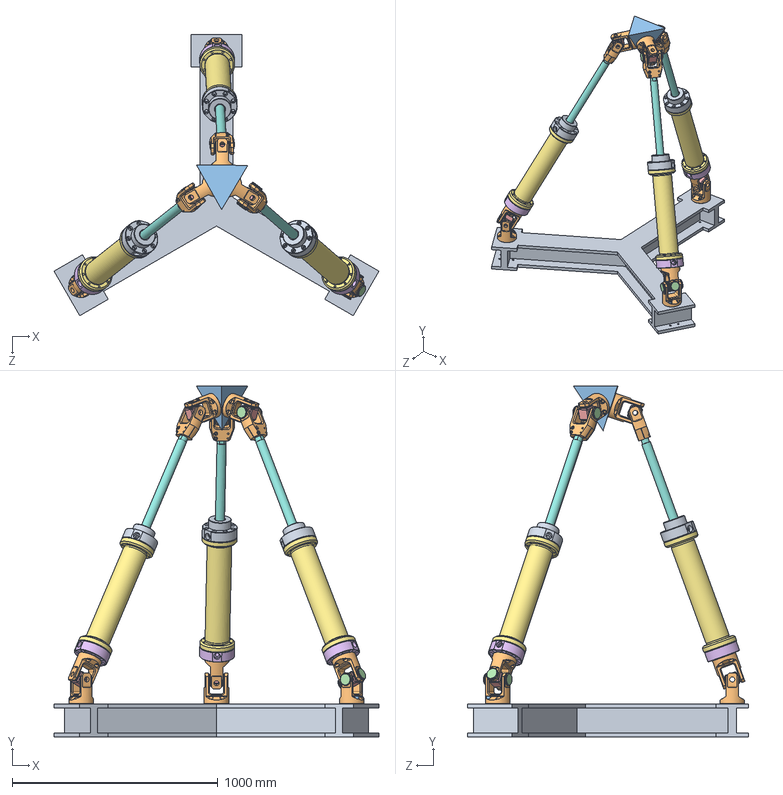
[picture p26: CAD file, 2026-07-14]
CAD/ably.SLDASM
1579.9 x 1706.5 x 1368.3 mm
base
rotate x 9
bolt_M14_60
BOLT_M27x2 x 6
joint_block x 6
connector1 x 3
pipe1 x 3
connecting_pipe x 3
connector2 x 3
rotate2 x 3
Triangular

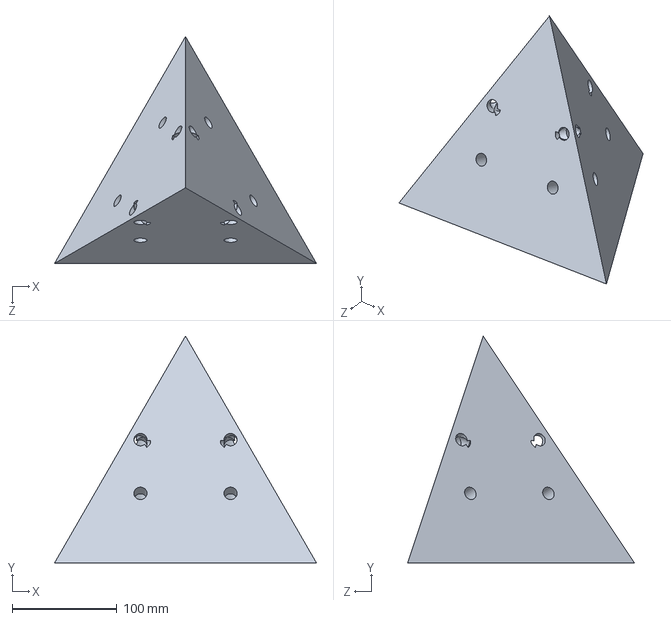
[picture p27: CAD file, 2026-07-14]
CAD/Triangular.SLDPRT
250.0 x 216.5 x 216.5 mm

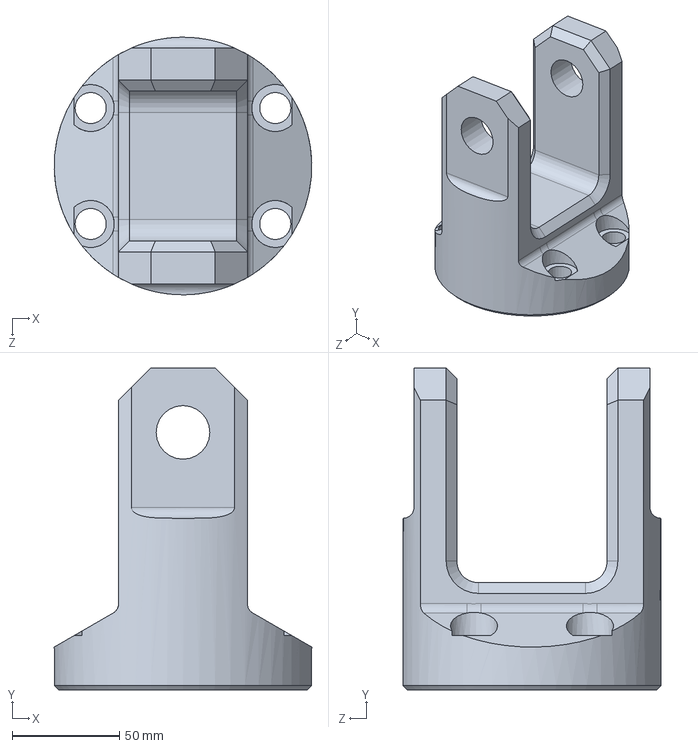
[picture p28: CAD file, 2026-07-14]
CAD/rotate.SLDPRT
120.0 x 150.0 x 120.0 mm

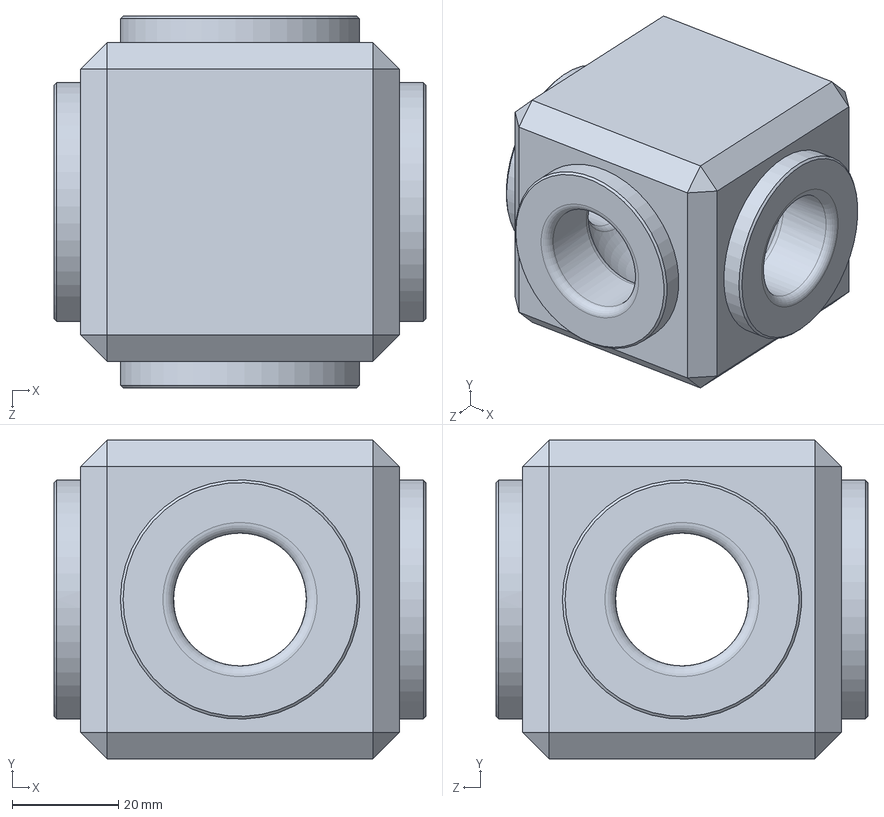
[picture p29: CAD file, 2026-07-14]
CAD/joint_block.SLDPRT
70.0 x 60.0 x 70.0 mm

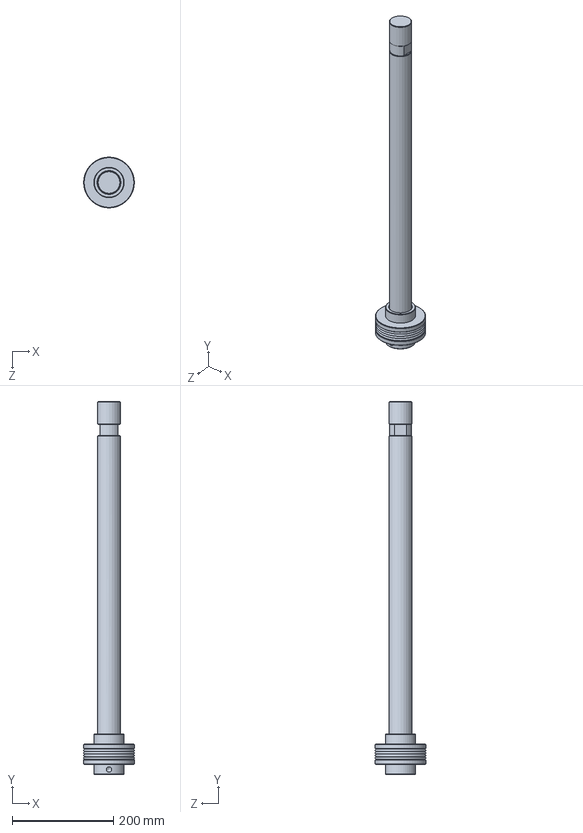
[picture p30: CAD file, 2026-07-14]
CAD/connecting_pipe.SLDPRT
100.0 x 736.0 x 99.9 mm

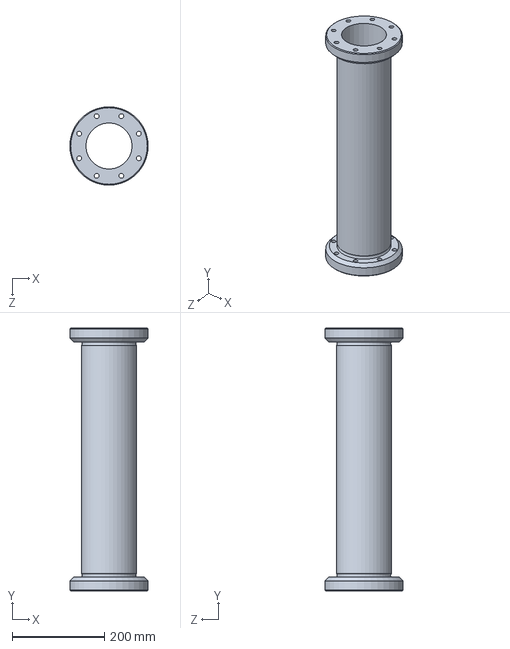
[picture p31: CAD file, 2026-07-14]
CAD/pipe1.SLDPRT
170.0 x 570.0 x 170.0 mm

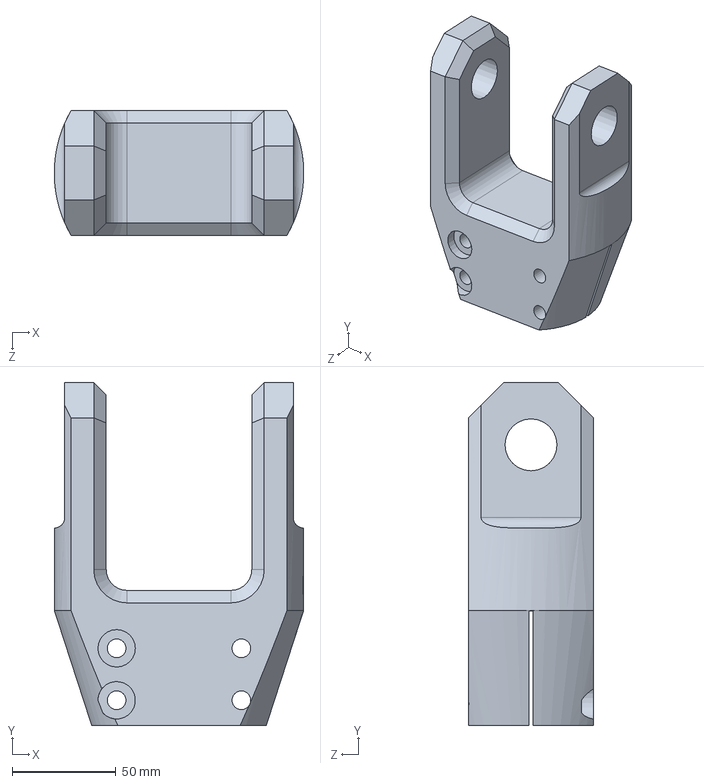
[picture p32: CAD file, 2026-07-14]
CAD/rotate2.SLDPRT
120.0 x 165.0 x 60.0 mm

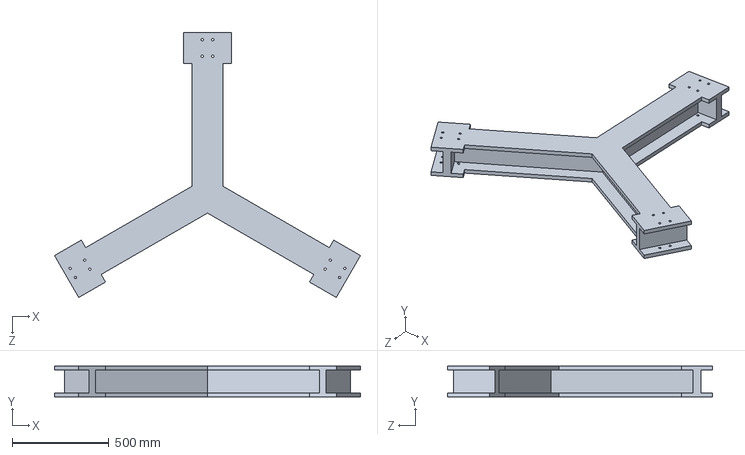
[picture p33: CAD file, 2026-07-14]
CAD/base.SLDPRT
1579.9 x 160.0 x 1368.3 mm

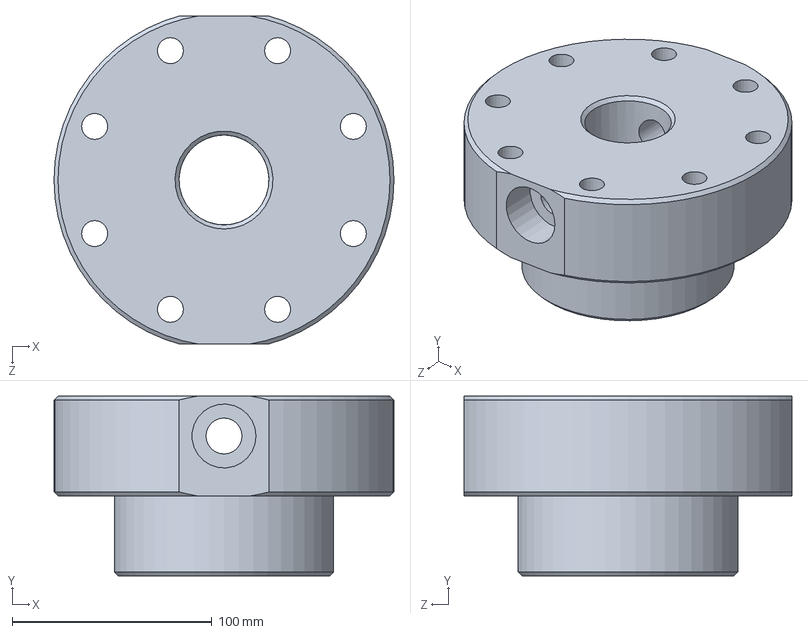
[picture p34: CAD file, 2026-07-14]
CAD/connector2.SLDPRT
170.0 x 90.0 x 164.0 mm

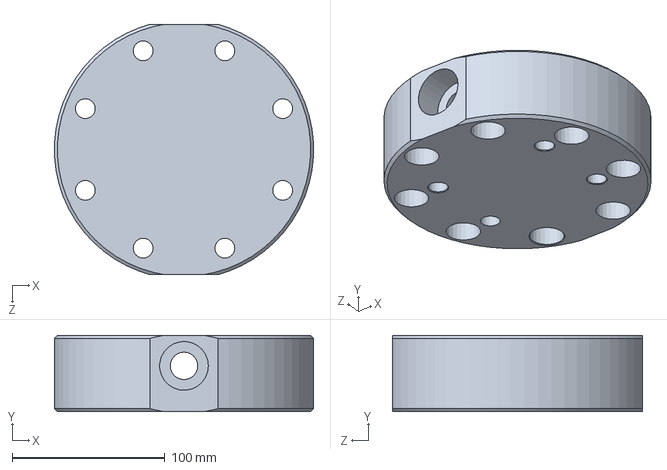
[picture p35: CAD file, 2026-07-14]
CAD/connector1.SLDPRT
169.8 x 50.0 x 164.0 mm

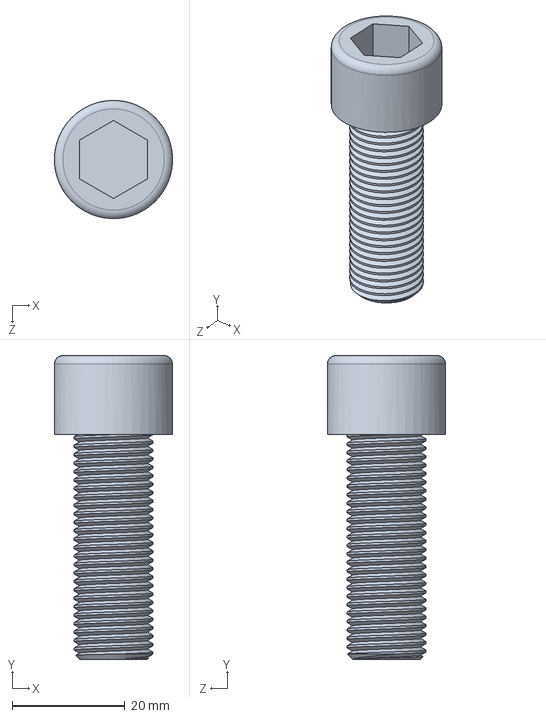
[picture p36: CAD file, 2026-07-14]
CAD/bolt_M14_60.SLDPRT
21.0 x 54.0 x 21.0 mm

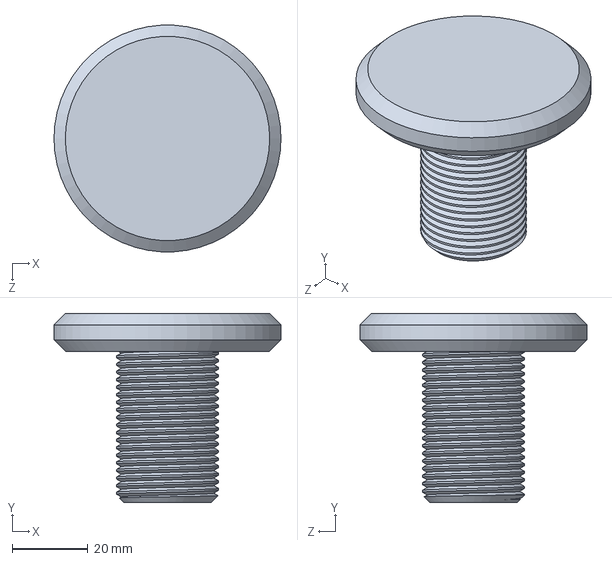
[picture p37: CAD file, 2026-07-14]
CAD/BOLT_M27x2.SLDPRT
60.0 x 50.0 x 59.9 mm

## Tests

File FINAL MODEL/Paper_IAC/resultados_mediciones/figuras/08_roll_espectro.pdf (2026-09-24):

!
p

10

0 | 10
| 1 Angular frequency ! (rad/s)

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
PSD of , (deg

2

s/rad)

At !p

: 24.1 dB (predicted 31.2 dB)

Without control (plate locked to base) With control
Prediction base"|S|

2

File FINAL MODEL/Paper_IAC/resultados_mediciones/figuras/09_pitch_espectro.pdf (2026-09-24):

!
p

10

0 | 10
| 1 Angular frequency ! (rad/s)

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
PSD of 3 (deg

2

s/rad)

At !p

: 11.1 dB (predicted 31.2 dB)

Without control (plate locked to base) With control
Prediction base"|S|

2

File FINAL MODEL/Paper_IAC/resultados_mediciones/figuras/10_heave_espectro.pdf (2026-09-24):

!
p

10

0 | 10
| 1 Angular frequency ! (rad/s)

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
PSD of z (m

2

s/rad)

At !p

: 10.4 dB (predicted 37.8 dB)

Without control (plate locked to base) With control
Prediction base"|S|

2

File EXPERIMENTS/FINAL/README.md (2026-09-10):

# Guía para correr archivos de MATLAB

En este folder hay siete archivos. Cuatro de ellos se usan para correr el sistema sin Filtro de Kalman con LQR, otros dos corren el sistema con Filtro de Kalman. El último archivo no está finalizado pero se puede usar en conjunto con otros para mejorar el sistema con Filtro de Kalman.

## Sistema sin Filtro de Kalman

Este sistema tiene mejor performance que el que tiene KF: corre más rápido, no tiene error y es más fácil de editar. El problema es que en el abstract del paper que mandamos a IAC dijimos que usabamos KF.

Para correr este sistema primero se deben abrir los archivos y correrlos en el orden: 

`marlup_identify.m` ➡️ `marlup_design.m` ➡️ `marlup_apply_lqr.m`

Una vez aplicados los cambios al modelo por el último programa, se puede correr el sistema `MARLUP_sinKF.slx`. Es importante no cambiarle el nombre al archivo .slx, o si se cambia, revisar todas las instancias en las que se cambia en los archivos anteriores y cambiarlo ahí también. 

Puede que la variable Hs del espectro PM para el olejae se haya reseteado a 0. En caso que no se vean olas, se debe de setear manualmente a un valor mayor a 0 (default: 0.5).

## Sistema sin Filtro de Kalman

Este sistema es mucho más lento que el anterior, pero utiliza el filtro de Kalman para estimar todas las variables de estado x. Se debe correr el archivo `MARLUP_FINAL.m` para guardar las variables en el espacio de trabajo antes de correr `MARLUP_conKF.slx`. 

Este segundo sistema tiene problemas con el bloque KF, por lo que todavía hay que revisarlo. También, el rechazo de error en este sistema no es tan bueno como en el anterior. Cabe revisar ambos sistemas para ver si al anterior se le puede agregar KF de una manera más sencilla, o si este se puede mejorar. 

## Trabajo restante

Según lo que se escibió en el resumen del paper a presentar en el IAC, se deben de cumplir las siguientes promesas:

- Que el sistema a controlar sea no-lineal, MIMO.
- Que el sistema presente disturbios en el ambiente producidos por un oleaje artificial (Espectro PM).
- Que el sistema presente sensado no-ideal, específicamente, ruido de medición, efectos de cuantización y limitaciones de muestreo. 
- Que el controlador sea de tipo óptimo.
- Que el sistema cuente con un estimador de estados (no específicamente un Filtro de Kalman, podemos diseñar uno más sencillo) para reconstruir los estados que no se pueden medir de la planta y mejorar el rechazo de disturbios en las mediciones no ideales.
- Que el sistema sea discreto para usar un PiL.
- Que el sistema se estabilice en menos de 10 segundos, con mínimo sobreimpulso, y que se quede vertical. 

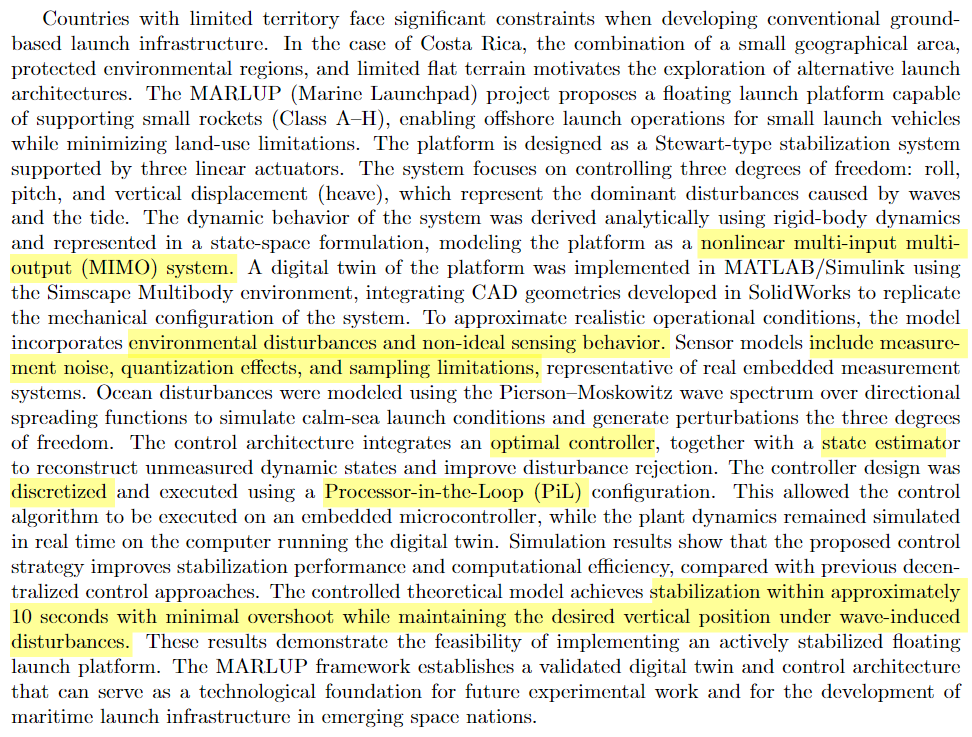
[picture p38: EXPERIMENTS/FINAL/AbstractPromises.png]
Promesas del abstract que faltan por cumplir. Title


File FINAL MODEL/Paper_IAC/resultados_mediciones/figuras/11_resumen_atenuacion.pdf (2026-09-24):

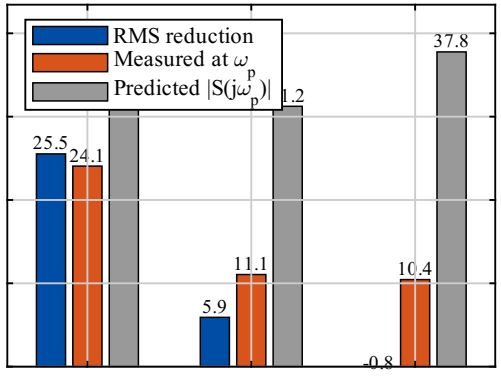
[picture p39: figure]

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
### Attenuation (dB)

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
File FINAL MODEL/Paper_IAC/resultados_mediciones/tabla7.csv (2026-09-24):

Eje | RMS_base | RMS_placa | Red_RMS | Red_dB | Pico_base | Pico_placa | Red_pico
Roll (deg) | 0.376850239109369 | 0.0199379246604398 | 18.9011768038778 | 25.5297768914225 | 0.713423071694942 | 0.0390264588800839 | 18.2804971849244
Pitch (deg) | 0.160070880694759 | 0.0810073738608419 | 1.97600382614225 | 5.91575562356311 | 0.376543910923016 | 0.158465926721666 | 2.37618217816875
Heave (m) | 0.0701755754611424 | 0.0767543133071606 | 0.914288362926381 | -0.778336158049515 | 0.124496879193563 | 0.0978473938312601 | 1.27235764100432

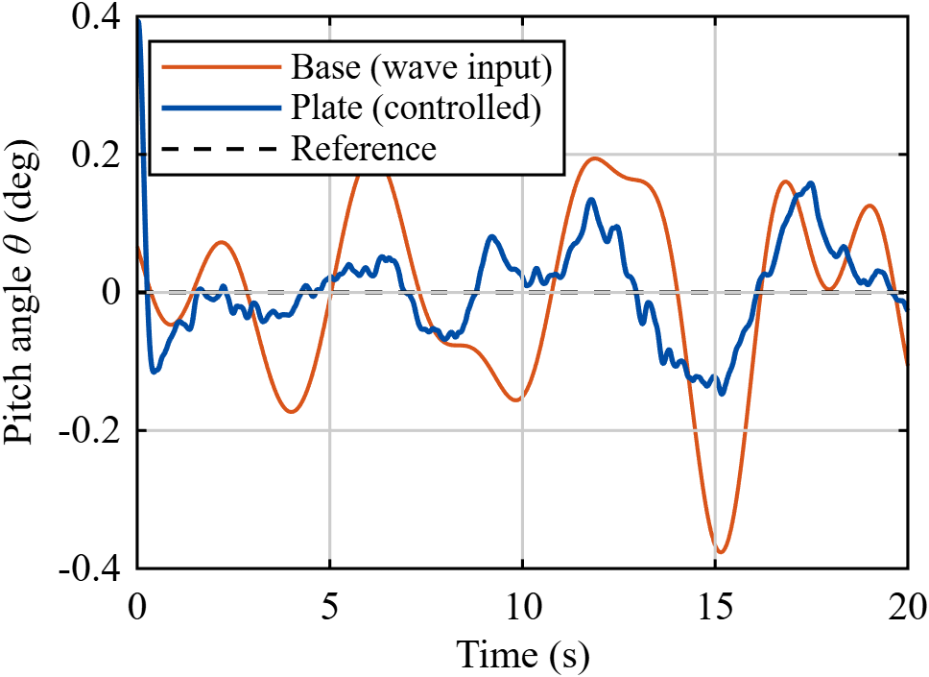
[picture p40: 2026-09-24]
FINAL MODEL/Paper_IAC/resultados_mediciones/figuras/02_pitch_tiempo.png

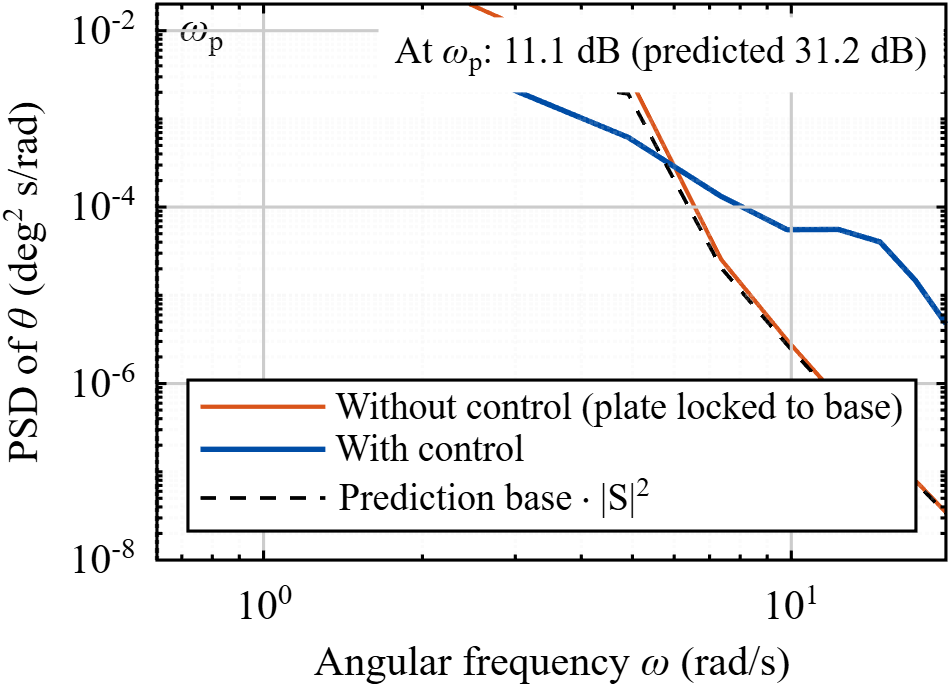
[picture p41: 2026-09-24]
FINAL MODEL/Paper_IAC/resultados_mediciones/figuras/09_pitch_espectro.png

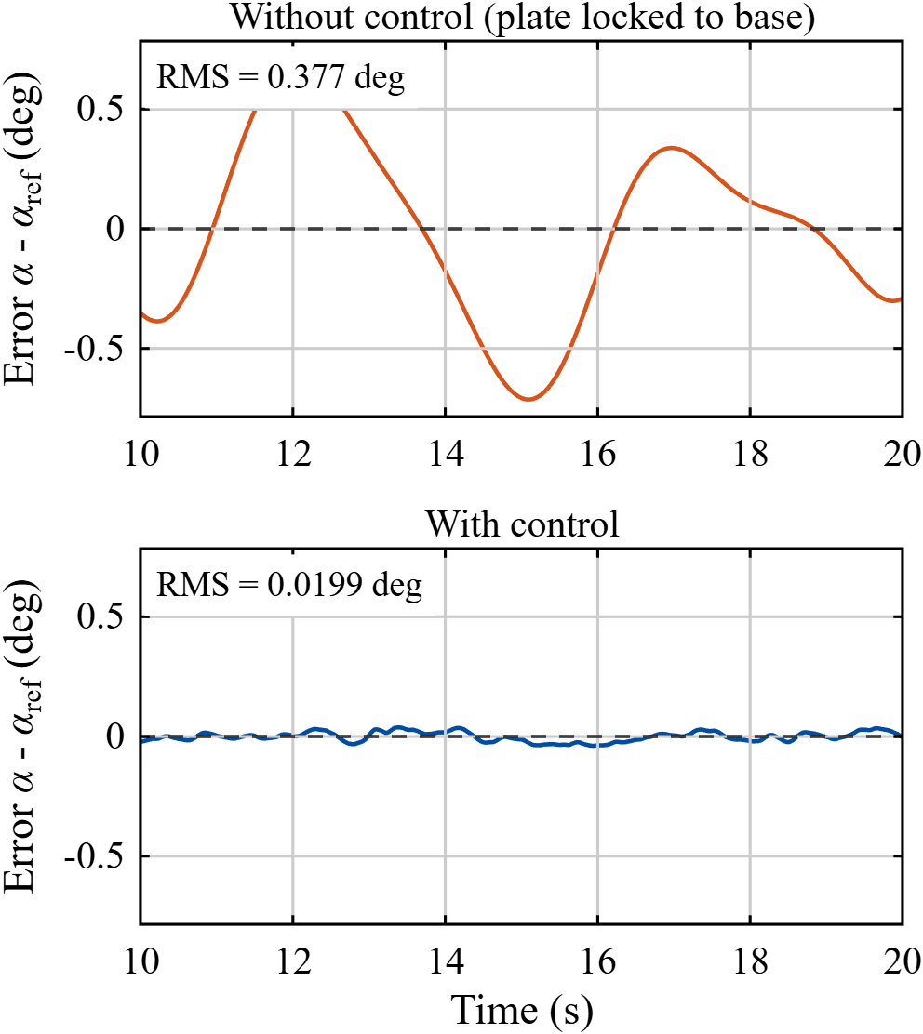
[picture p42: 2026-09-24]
FINAL MODEL/Paper_IAC/resultados_mediciones/figuras/05_roll_antes_despues.png

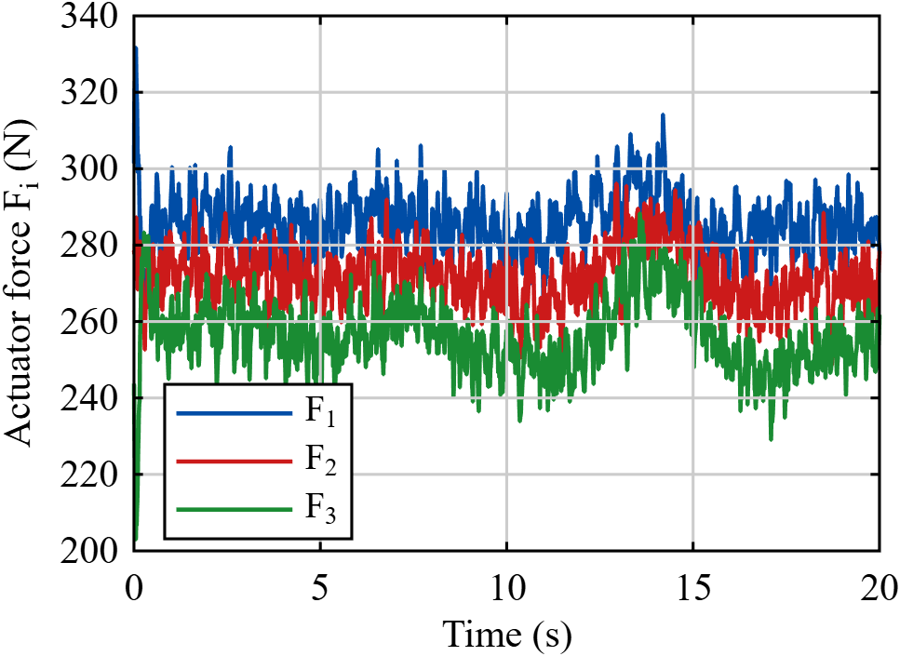
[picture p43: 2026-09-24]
FINAL MODEL/Paper_IAC/resultados_mediciones/figuras/04_fuerzas_actuador.png

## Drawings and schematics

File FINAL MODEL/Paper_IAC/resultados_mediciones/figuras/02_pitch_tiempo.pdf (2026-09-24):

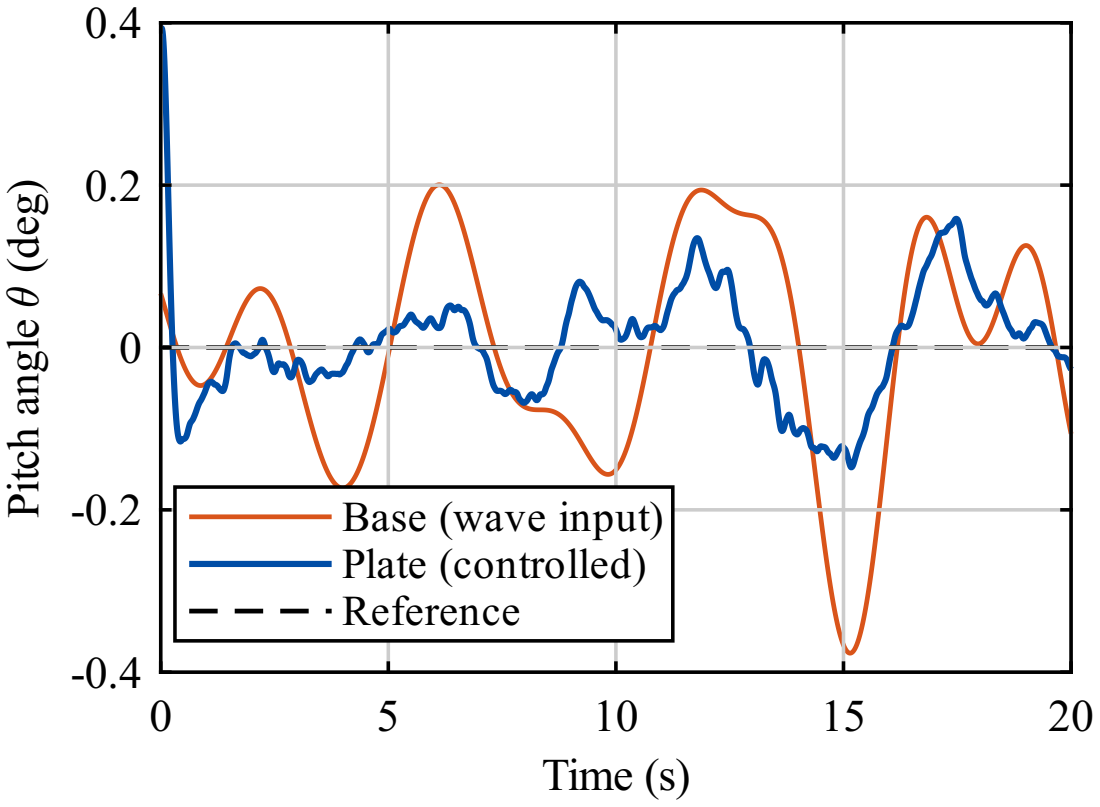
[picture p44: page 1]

Pitch angle 3 (deg)

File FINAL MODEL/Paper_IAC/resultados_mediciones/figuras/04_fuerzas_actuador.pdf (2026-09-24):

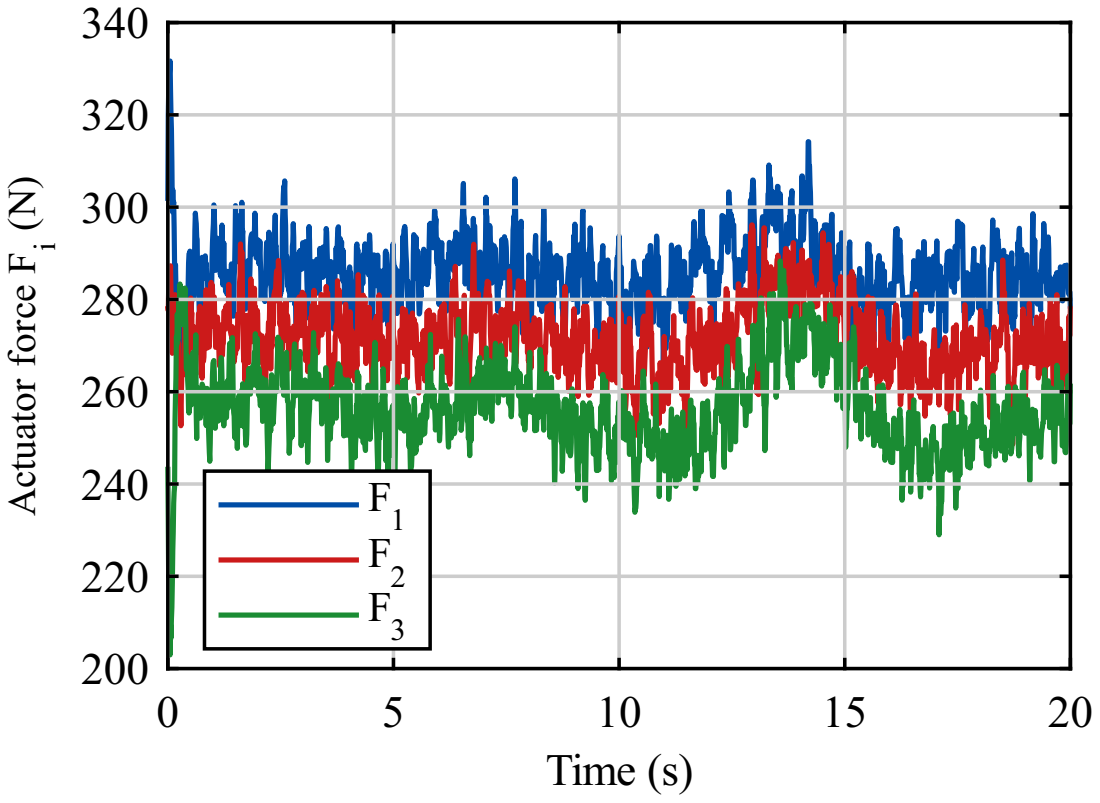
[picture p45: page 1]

Actuator force Fi (N)

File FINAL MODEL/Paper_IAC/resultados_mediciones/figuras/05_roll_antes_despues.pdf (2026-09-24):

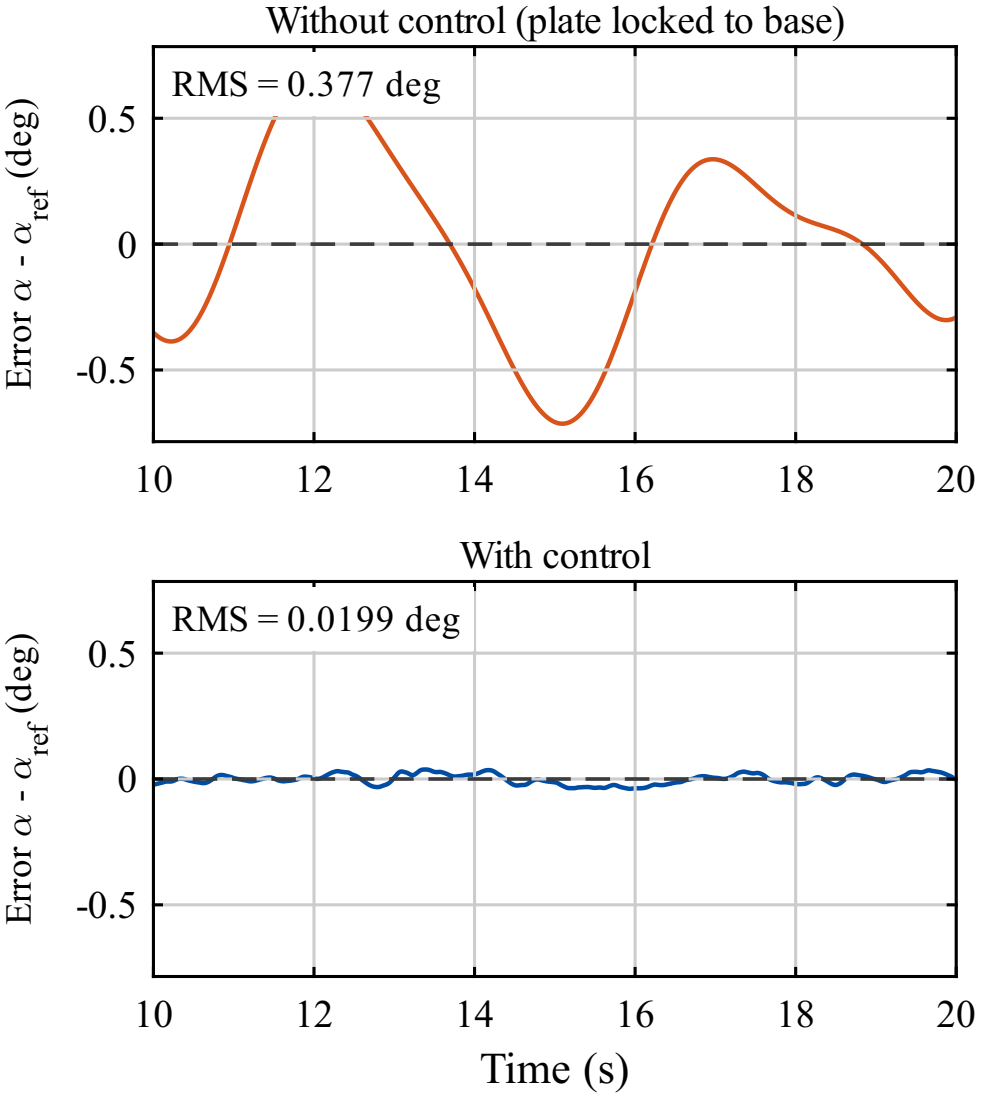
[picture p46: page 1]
Error , - ,ref; (deg); With control; Time (s); RMS = 0.0199 deg

Without control (plate locked to base)
RMS = 0.377 deg

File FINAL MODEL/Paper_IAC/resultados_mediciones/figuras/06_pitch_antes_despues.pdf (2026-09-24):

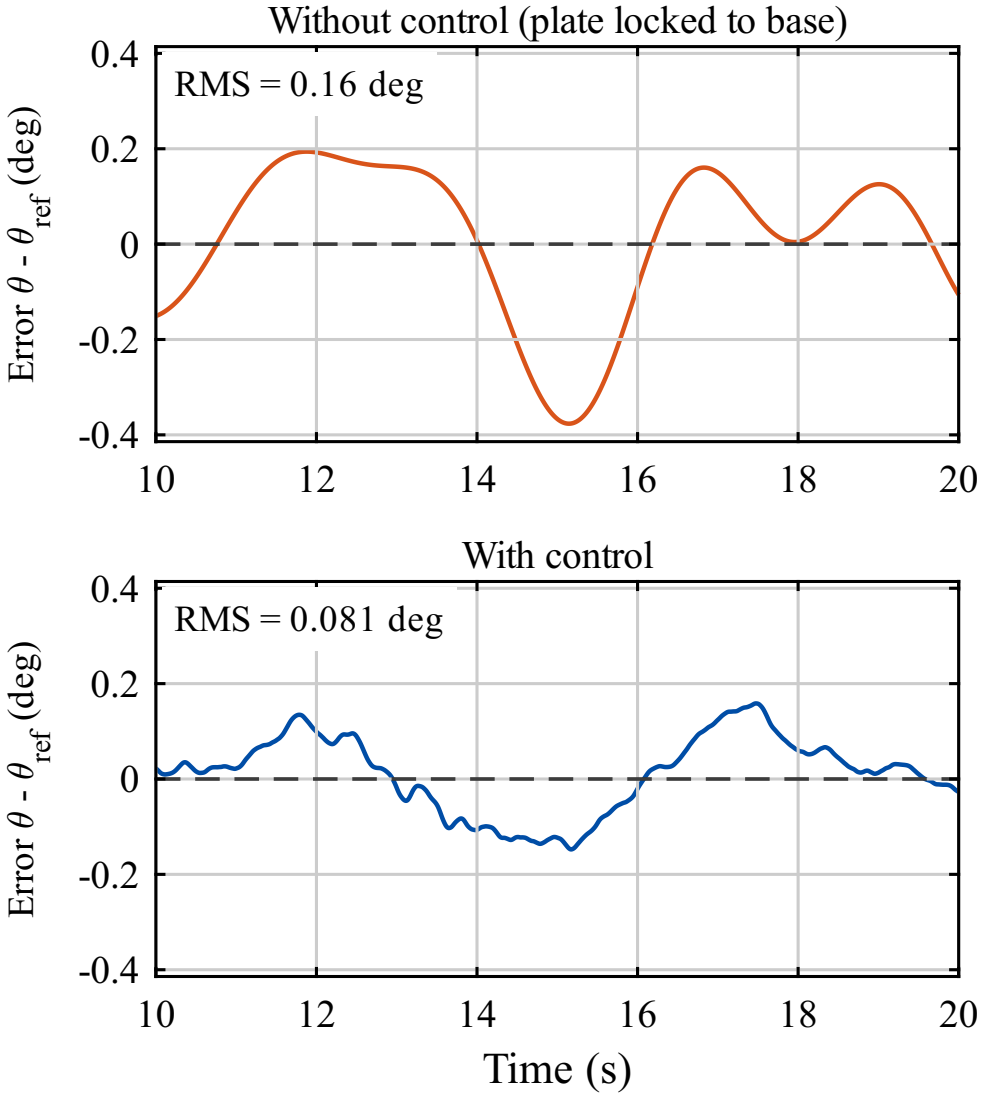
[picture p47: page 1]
Error 3 - 3; ref; (deg); With control; Time (s); RMS = 0.081 deg

Without control (plate locked to base)
RMS = 0.16 deg

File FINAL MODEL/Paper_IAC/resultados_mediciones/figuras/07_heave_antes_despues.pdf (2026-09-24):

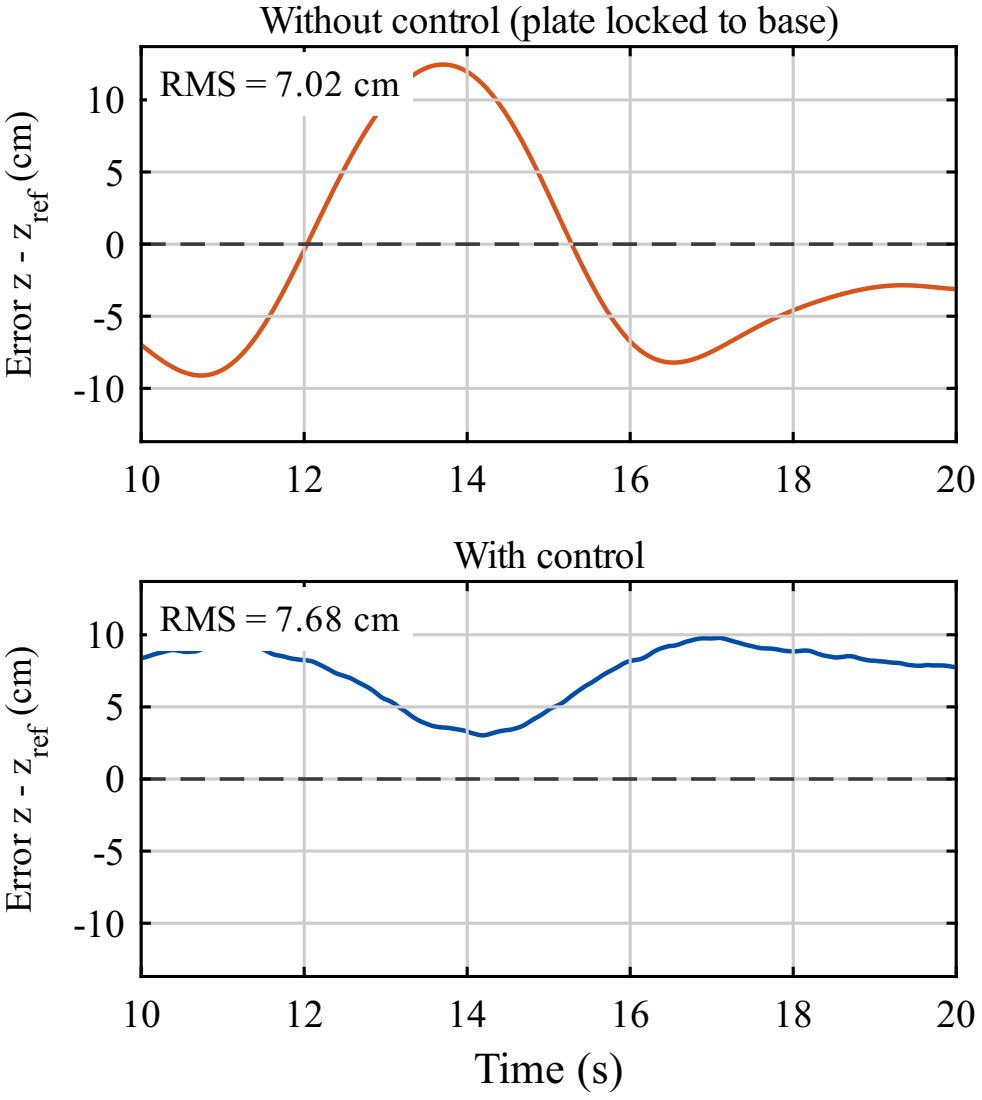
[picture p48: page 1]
Error z - z; ref; RMS = 7.02 cm; With control; Time (s); RMS = 7.68 cm

Without control (plate locked to base)

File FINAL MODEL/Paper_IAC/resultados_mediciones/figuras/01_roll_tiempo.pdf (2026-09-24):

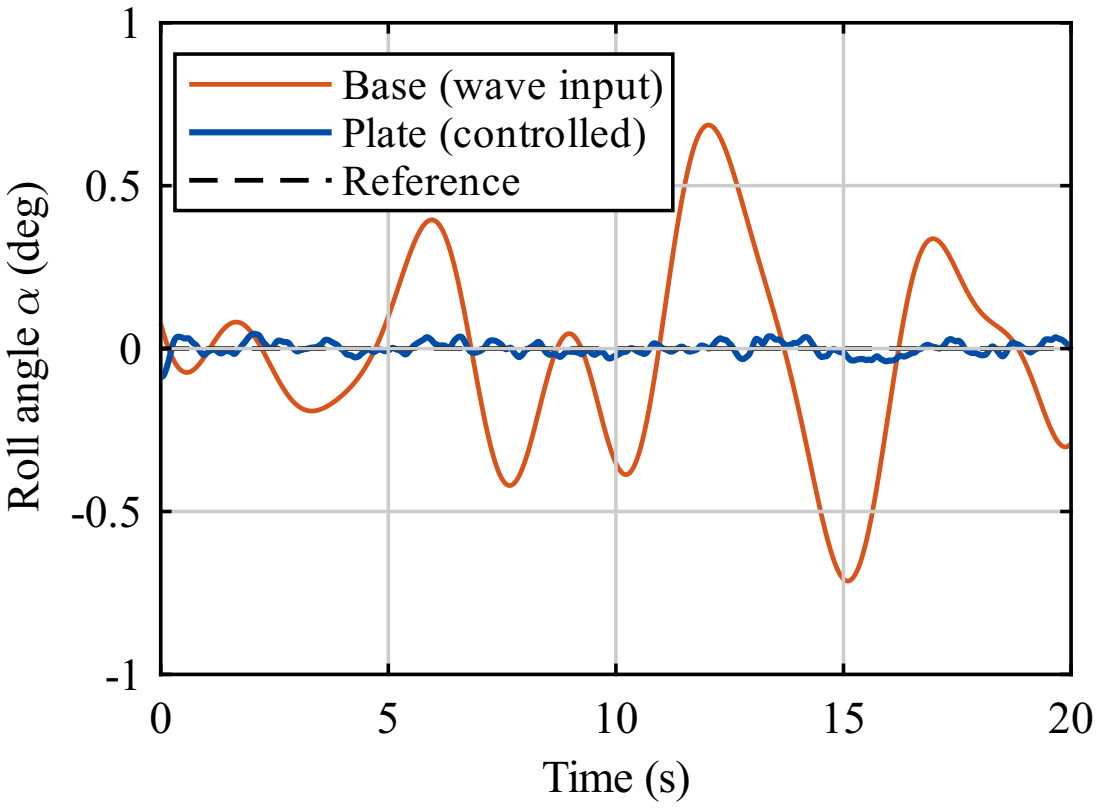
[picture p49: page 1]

Roll angle , (deg)

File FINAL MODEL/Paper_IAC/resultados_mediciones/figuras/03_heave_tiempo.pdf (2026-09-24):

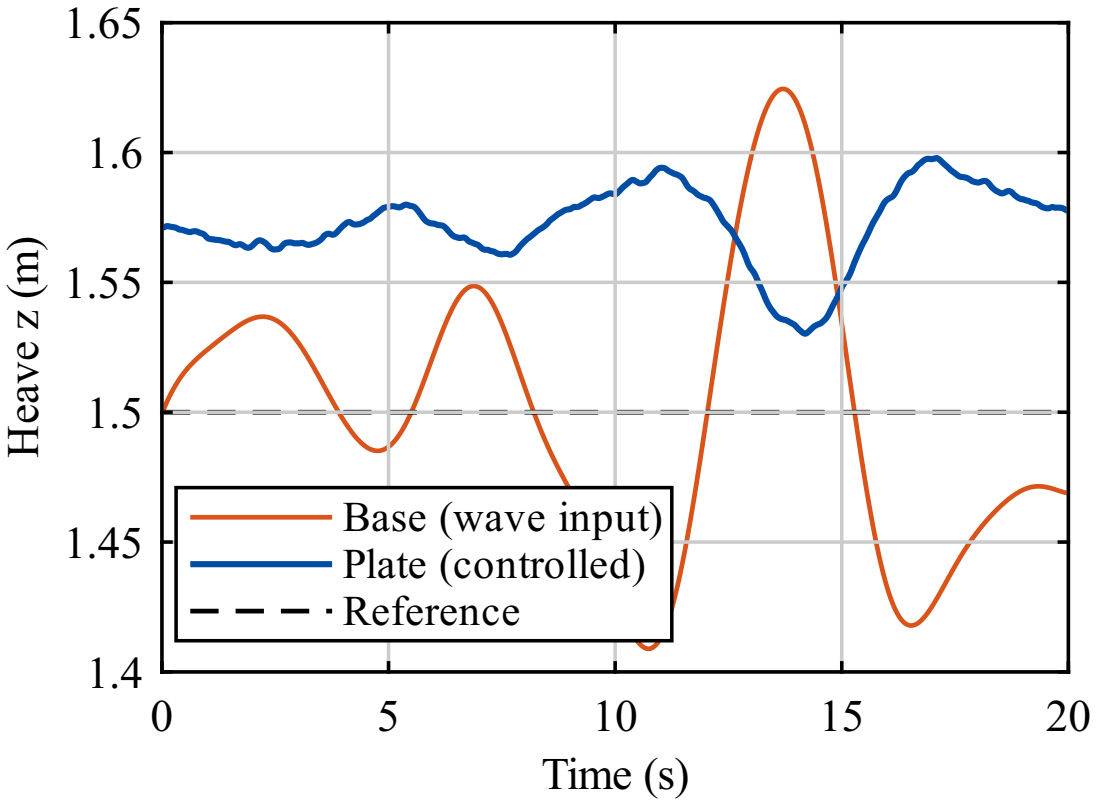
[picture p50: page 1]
Heave z (m)

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

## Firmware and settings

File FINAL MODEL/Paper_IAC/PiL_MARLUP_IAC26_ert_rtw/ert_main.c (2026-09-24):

/*
 * Academic License - for use in teaching, academic research, and meeting
 * course requirements at degree granting institutions only.  Not for
 * government, commercial, or other organizational use.
 *
 * File: ert_main.c
 *
 * Code generated for Simulink model 'PiL_MARLUP_IAC26'.
 *
 * Model version                  : 4.24
 * Simulink Coder version         : 26.1 (R2026a) 20-Nov-2025
 * C/C++ source code generated on : Thu Sep 24 20:12:34 2026
 *
 * Target selection: ert.tlc
 * Embedded hardware selection: ARM Compatible->ARM Cortex-M
 * Code generation objectives: Unspecified
 * Validation result: Not run
 */

#include "PiL_MARLUP_IAC26.h"
#include "rtwtypes.h"
#include "MW_target_hardware_resources.h"

volatile int IsrOverrun = 0;
static boolean_T OverrunFlag = 0;
void rt_OneStep(void)
{
  /* Check for overrun. Protect OverrunFlag against preemption */
  if (OverrunFlag++) {
    IsrOverrun = 1;
    OverrunFlag--;
    return;
  }

  __enable_irq();
  PiL_MARLUP_IAC26_step();

  /* Get model outputs here */
  __disable_irq();
  OverrunFlag--;
}

volatile boolean_T stopRequested;
volatile boolean_T runModel;
int main(int argc, char **argv)
{
  float modelBaseRate = 0.01;
  float systemClock = 84.0;

  /* Initialize variables */
  stopRequested = false;
  runModel = false;

#if !defined(MW_FREERTOS) && defined(MW_MULTI_TASKING_MODE) && (MW_MULTI_TASKING_MODE == 1)

  MW_ASM (" SVC #1");

#endif

  ;

  // Start Peripheral initialization imported from STM32CubeMX project;
  void MX_DMA_Init(void);
  void MX_GPIO_Init(void);
  void MX_USART2_UART_Init(void);
  HAL_Init();
  SystemClock_Config();
  PeriphCommonClock_Config();
  MX_DMA_Init();
  MX_GPIO_Init();
  MX_USART2_UART_Init();

  // End Peripheral initialization imported from STM32CubeMX project;
  rtmSetErrorStatus(PiL_MARLUP_IAC26_M, 0);
  PiL_MARLUP_IAC26_initialize();
  __disable_irq();
  ARMCM_SysTick_Config(modelBaseRate);
  runModel =
    rtmGetErrorStatus(PiL_MARLUP_IAC26_M) == (NULL);
  __enable_irq();
  __enable_irq();
  while (runModel) {
    stopRequested = !(
                      rtmGetErrorStatus(PiL_MARLUP_IAC26_M) == (NULL));
  }

  /* Terminate model */
  PiL_MARLUP_IAC26_terminate();

#if !defined(MW_FREERTOS) && !defined(USE_RTX)

  (void) systemClock;

#endif

  ;
  __disable_irq();
  return 0;
}

/*
 * File trailer for generated code.
 *
 * [EOF]
 */

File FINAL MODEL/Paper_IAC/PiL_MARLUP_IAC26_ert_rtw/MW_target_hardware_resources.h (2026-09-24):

#ifndef PORTABLE_WORDSIZES
#ifdef __MW_TARGET_USE_HARDWARE_RESOURCES_H__
#ifndef __MW_TARGET_HARDWARE_RESOURCES_H__
#define __MW_TARGET_HARDWARE_RESOURCES_H__

#define MW_MULTI_TASKING_MODE 1
#include "mw_stm32_board_header.h"
#include "SysTickScheduler.h"
#include "arm_cortex_m_multitasking.h"

#define MW_USECODERTARGET 1
#define MW_TARGETHARDWARE STM32F4xx Based
#define MW_EXTMODEPROTOCOLINFO_SERIAL_HOSTINTERFACE Simulink
#define MW_EXTMODEPROTOCOLINFO_SERIAL_LOGGINGBUFFERAUTO 1
#define MW_EXTMODEPROTOCOLINFO_SERIAL_LOGGINGBUFFERSIZE 1024
#define MW_EXTMODEPROTOCOLINFO_SERIAL_LOGGINGBUFFERNUM 3
#define MW_EXTMODEPROTOCOLINFO_SERIAL_MAXCONTIGSAMPLES 10
#define MW_EXTMODEPROTOCOLINFO_CAN_HOSTINTERFACE Simulink
#define MW_EXTMODEPROTOCOLINFO_CAN_LOGGINGBUFFERAUTO 1
#define MW_EXTMODEPROTOCOLINFO_CAN_LOGGINGBUFFERSIZE 1000
#define MW_EXTMODEPROTOCOLINFO_CAN_LOGGINGBUFFERNUM 3
#define MW_EXTMODEPROTOCOLINFO_CAN_MAXCONTIGSAMPLES 10
#define MW_CONNECTIONINFO_SERIAL_BAUDRATE stm32cube.codegen.getConnectivityBaudrate(hCS)
#define MW_CONNECTIONINFO_SERIAL_COMPORT stm32cube.codegen.getConnectivityCOMPort(hCS)
#define MW_CONNECTIONINFO_SERIAL_VERBOSE 1
#define MW_CONNECTIONINFO_TCPIP_IPADDRESS stm32cube.parameters.EthernetConfigIPAddressExternalMode
#define MW_CONNECTIONINFO_TCPIP_PORT 17725
#define MW_CONNECTIONINFO_TCPIP_VERBOSE 1
#define MW_CONNECTIONINFO_CAN_CANVENDOR matlab:stm32cube.codegen.getXCPonCANConnectivity(hCS,'Vendor')
#define MW_CONNECTIONINFO_CAN_CANDEVICE matlab:stm32cube.codegen.getXCPonCANConnectivity(hCS,'Device')
#define MW_CONNECTIONINFO_CAN_CANCHANNEL stm32cube.codegen.getXCPonCANConnectivity(hCS,'Channel')
#define MW_CONNECTIONINFO_CAN_BUSSPEED stm32cube.codegen.getXCPonCANConnectivity(hCS,'Baudrate')
#define MW_CONNECTIONINFO_CAN_CANIDCOMMAND stm32cube.codegen.getXCPonCANConnectivity(hCS,'CANIDCommand')
#define MW_CONNECTIONINFO_CAN_CANIDRESPONSE stm32cube.codegen.getXCPonCANConnectivity(hCS,'CANIDResponse')
#define MW_CONNECTIONINFO_CAN_ISCANIDEXTENDED stm32cube.codegen.getXCPonCANConnectivity(hCS,'IsCANIDExtended')
#define MW_CONNECTIONINFO_CAN_VERBOSE 1
#define MW_EXTMODE_CONFIGURATION Serial
#define MW_EXTMODE_TARGETWAITFORCONNECTION 1
#define MW_EXTMODE_USEREALTIMESTAMPLOGGING 1
#define MW_RTOS Baremetal
#define MW_RTOSBASERATETASKPRIORITY 40
#define MW_SCHEDULER_INTERRUPT_SOURCE 0
#define MW_RUNTIME_BUILDACTION 1
#define MW_RUNTIME_RUNTIMELIBRARY 0
#define MW_RUNTIME_FLOATABI 2
#define MW_RUNTIME_FFPCONTRACTION 1
#define MW_RUNTIME_DISABLEPARALLELBUILD 0
#define MW_RUNTIME_GENERATEIDEPROJECT 0
#define MW_STM32CUBEMX_PROJECTFILEBUTTON 
#define MW_STM32CUBEMX_CREATEPROJECTFILEBUTTON 
#define MW_STM32CUBEMX_LAUNCHPROJECTFILEBUTTON 
#define MW_STM32CUBEMX_PROJECTFILE D:/RESEARCH/MARLUP/MARLUP/FINAL MODEL/Paper_IAC/MARLUP_PiL/MARLUP_PiL.ioc
#define MW_STM32CUBEMX_DEVICEID STM32F446R(C-E)Tx
#define MW_STM32CUBEMX_FAMILY STM32F4
#define MW_STM32CUBEMX_LINKERCUSTOMCONFIGUREMODULE 48
#define MW_STM32CUBEMX_LINKEREDIT <Select linker file>
#define MW_STM32CUBEMX_LINKERBROWSE 
#define MW_STM32CUBEMX_CONNECTIVITYMODE 0
#define MW_STM32CUBEMX_CONNECTIONPORT 0
#define MW_STM32CUBEMX_FREQUENCY 4000
#define MW_STM32CUBEMX_MODE 0
#define MW_STM32CUBEMX_ACCESSPORT 0
#define MW_STM32CUBEMX_RESETMODE 0
#define MW_STM32CUBEMX_AUTODETECTBOARD 1
#define MW_STM32CUBEMX_DEVICELIST -1
#define MW_STM32CUBEMX_DEVICELISTREFRESH 
#define MW_CLOCKING_CPUCLOCKRATEMHZ 84.000000
#define MW_CONNECTION_SERIALCONFIGUREMODULE 48
#define MW_CONNECTION_SERIALMODULE 1
#define MW_CONNECTION_SERIALPORT -1
#define MW_CONNECTION_ETHERNETCONFIGUREMODULE 48
#define MW_CONNECTION_ETHERNETPORT 17725.000000
#define MW_CONNECTION_CANCONFIGUREMODULE 48
#define MW_CONNECTION_CANMODULE 0
#define MW_CONNECTION_BAUDRATE 1000000
#define MW_CONNECTION_CANREADSOURCE 0
#define MW_CONNECTION_CANVENDOR -1
#define MW_CONNECTION_CANDEVICE -1
#define MW_CONNECTION_CANCHANNEL -1
#define MW_CONNECTION_ISCANIDEXTENDED 48
#define MW_CONNECTION_CANIDCOMMAND 2
#define MW_CONNECTION_CANIDRESPONSE 3
#define MW_CONNECTION_SERIALPORTREFRESH 
#define MW_CONNECTIVITY_REFRESH 
#define MW_SIMULINKIO_MODELTRANSPORTDATAFCN stm32cube.connectedIO.getConfigSetInfo
#define MW_SIMULINKIO_SERVERDEPLOYFCN stm32cube.connectedIO.updateServer
#define MW_SIMULINKIO_VALIDATESERVERFCN stm32cube.connectedIO.validateIoServer
#define MW_SIMULINKIO_INTERFACE 0
#define MW_SIMULINKIO_VALIDATEBEFORECONNECTFCN stm32cube.connectedIO.connectedIOModelValidation
#define MW_SIMULINKIO_CONNECTEDIOSUPPORTEDBLOCKS DigitalPortRead,DigitalPortWrite,PWMOutput,AnalogInput,I2CControllerRead,I2CControllerWrite,SPIControllerTransmit,SPIControllerReceive,SPIControllerTransfer,LSM6DS3Block,LSM6DS3HBlock,LSM6DSLBlock,LSM6DSMBlock,LSM6DSRBlock,LSM6DSOBlock,LSM303CBlock,LIS3MDLBlock,LPS22HBBlock,HTS221Block,BMI160Block,ADXL34xBlock,CCS811Block,ICM20948Block,LIS3DHBlock,RegisterRW,BNO055Block,MPU6050Block,MPU9250Block
#define MW_CONNECTEDIO_CONNECTEDIOMODE 0
#define MW_CONNECTEDIO_ACTIONONOVERRUN 0
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

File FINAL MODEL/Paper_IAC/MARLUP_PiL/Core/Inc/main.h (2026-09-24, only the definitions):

#define B1_Pin LL_GPIO_PIN_13
#define B1_GPIO_Port GPIOC
#define USART_TX_Pin LL_GPIO_PIN_2
#define USART_TX_GPIO_Port GPIOA
#define USART_RX_Pin LL_GPIO_PIN_3
#define USART_RX_GPIO_Port GPIOA
#define LD2_Pin LL_GPIO_PIN_5
#define LD2_GPIO_Port GPIOA
#define TMS_Pin LL_GPIO_PIN_13
#define TMS_GPIO_Port GPIOA
#define TCK_Pin LL_GPIO_PIN_14
#define TCK_GPIO_Port GPIOA
#define SWO_Pin LL_GPIO_PIN_3
#define SWO_GPIO_Port GPIOB

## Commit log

2026-07-14 Added project files, organization
    [BOLT_M27x2.SLDPRT, Triangular.SLDPRT, ably.SLDASM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]
2026-07-16 refactor: tidy wave disturbance wiring and tap signals before joint
    Rearrange the block diagram around the wave subsystem: straighten the
    Oleaje-to-4DOF-joint routing (heave->pz, roll->qx, pitch->qy) and move
    the logging Mux/Scope taps to the signals feeding the joint instead of
    the joint's sensed outputs.
2026-07-16 refactor: clean up control loop diagram layout
    Tidy the main control subsystem: label the rad-to-deg display gains
    (180/pi), route roll/pitch/heave measurements through a single mux to
    the feedback path and scope, and untangle the CONTROL and REFERENCIA
    area wiring. No functional changes to the loop.
2026-07-16 fix: resolve CAD geometry paths so the model assembles on any machine
    File Solid blocks pointed to absolute .SLDPRT paths from the original
    author's machine, breaking assembly (missing geometry, inertia and
    frame errors) for everyone else. Rewrite every geometry FileName to the
    bare file name and add the CAD parts folder (Files/Referencia/Sistema
    escalado) to the MATLAB path from Script_MARLUP_Final.m, so the blocks
    resolve the parts on any clone of the repo.
2026-07-18 refactor: restructure block diagram for easier debugging
    Rework the model layout with heavier reorganization of blocks and
    signal routing so faults are easier to trace during simulation.
2026-07-21 refactor: reorganize repo into CAD, DOCS and IAC folders
    Introduce a cleaner top-level layout: CAD/ for the SolidWorks parts,
    DOCS/ for the project reports, and IAC/ for the active model and
    script. Update the CAD addpath in Script_MARLUP_Final.m to the new
    CAD/ location so File Solid blocks still resolve their geometry, and
    drop the obsolete LQR ramp-test models.
    [BOLT_M27x2.SLDPRT, Triangular.SLDPRT, ably.SLDASM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]
2026-07-21 refactor: finish repo reorg, keep CEC figures in DOCS/FIGS
    Remove the leftover Files/ tree now that the active model, script, CAD
    parts and reports live under IAC/, CAD/ and DOCS/. Relocate the CEC
    video figures and plots to DOCS/FIGS/ instead of deleting them. The
    scaled-prototype reference and old model variants remain in git
    history if ever needed.
    [BOLT_M27x2.SLDPRT, Triangular.SLDPRT, ably.SLDASM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]
2026-07-21 docs: update CLAUDE.md to match CAD/DOCS/IAC repo reorg
    Repository was restructured from Files/ into CAD/DOCS/IAC (main.m,
    MARLUP_IAC.slx) but CLAUDE.md still referenced the old paths and the
    now-removed Files/Referencia historical content.
2026-07-21 docs: update CLAUDE.md with marlup_init.m / marlup_model.slx names
    The reorg doc still referenced the pre-rename main.m and
    MARLUP_IAC.slx; point it at the current marlup_init.m and
    marlup_model.slx instead.
2026-07-21 feat: add per-person experiment sandboxes under EXPERIMENTS/
    Adds Aaron/, Alvaro/, and Will/ sandbox copies of the script+model
    pair for independent tuning experiments, and documents a known
    addpath bug in those copies (CAD path resolves one level too deep).
2026-07-21 docs: rewrite README with project explanation, equations, and figures
    Expands the placeholder README into a full engineering-level overview:
    project context across both stages, platform geometry and state-space
    model, actuator/sensor specs, wave-disturbance spectrum, the LQR/Kalman/
    LQI control design, PIL/SIL verification, and simulation results —
    illustrated with the report figures already in DOCS/FIGS/.
2026-07-21 docs: rewrite README as a brief intro with repo tree
    Replace the placeholder README with a short project description, the
    MARLUP.gif demo, and a directory tree covering IAC/CAD/DOCS. Track the
    gif referenced by the README so it renders on any clone.
2026-07-23 feat(control): implementar PID multivariable con desacople por pseudoinversaReemplaza el esquema PID por pistón individual por tres PID discretos quecierran sobre roll, pitch y heave, con salida en e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
2026-08-10 (refactor): blocks diagram and the script has been modified to debug pitch controller
2026-08-12 My last commit, a simulation of 120 seconds of active stabilization with little waves(20 cm)
2026-08-23 feat(PISTON_MODEL): a new piston model was added
2026-09-10 seccion FINAL a EXPERIMENTS, asi como un README para explicar como se usan los archivos
2026-09-10 actualiza experimentos y resultados de MARLUP
2026-09-11 Piezas en su lugar y orden de archivos MARLUP SIN KF
2026-09-17 actualiza simulacion de oleaje y documentacion
    - Mejora la visualizacion del oleaje con fondo claro y paleta de agua.\n- Actualiza el modelo MARLUP_sinKF y los archivos de simulacion de Aaron.\n- Añade PiL_MARLUP, sea_sim_day y nuevos resultados 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
2026-09-24 Annadir Integrador a la planta
2026-09-24 funciona con Observador y PiL
    [tabla7.csv]

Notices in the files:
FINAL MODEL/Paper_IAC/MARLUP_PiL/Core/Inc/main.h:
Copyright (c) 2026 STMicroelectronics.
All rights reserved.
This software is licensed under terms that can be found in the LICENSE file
